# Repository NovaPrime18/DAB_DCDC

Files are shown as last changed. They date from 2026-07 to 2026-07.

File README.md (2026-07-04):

# 10kW Dual Active Bridge DC-DC Converter




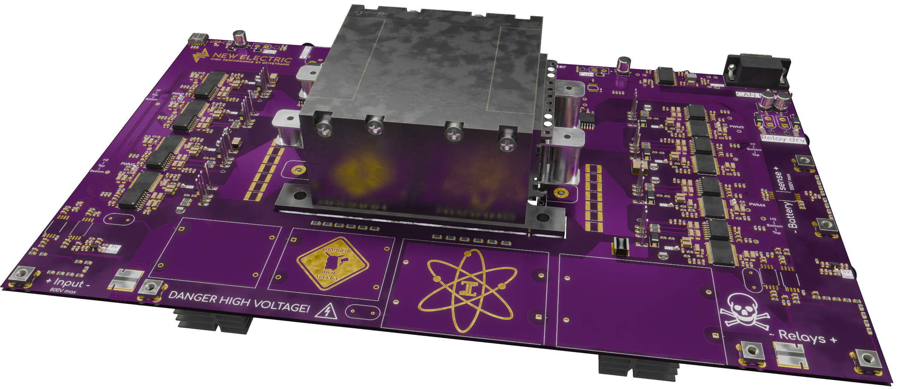
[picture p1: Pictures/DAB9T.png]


Hardware files for a high-power, high-frequency DC-DC converter PCB, developed as a
prototype module for a modular 500kW off-grid EV DC fast charger. The board implements
a Dual Active Bridge (DAB) topology with a planar transformer, isolated gate drivers and
sensing, and on-board water/air cooling provisions for the power stage.

This board is a single prototype module. Multiple modules are intended to be run in
parallel and/or series to scale up to the full 500kW system.

---

## Key specifications

| Parameter | Value |
|---|---|
| Topology | Dual Active Bridge (DAB) |
| Input voltage | 500–800V DC |
| Output voltage | 250–1000V DC (peak efficiency at 666V) |
| Output power | ~10kW per module |
| Output current | Primary 15A (22A peak), Secondary 17A (25A peak) |
| Switching frequency | 100kHz |
| Isolation | Galvanic, via transformer (10,000V dielectric strength primary/secondary) |
| Transformer | Payton Planar, 24:20 turns ratio, 35µH total leakage inductance |
| Control | TI controlCARD via CAN bus, phase-shift power regulation |
| PCB | 6 layers, 70µm (2oz) copper, 2mm FR4 |
| Secondary switches | Microchip MSC035SMA170B4 SiC MOSFETs (1700V) |
| Clearance / creepage | 3mm (primary) / 3.5mm (secondary), per IPC-2221 / IEC-60664 |
| Voltage derating | 1.7x on HV secondary components |
| Cooling | Fin-stack air-cooled heatsinks or aluminum liquid-cooling plate (SiCFETs + transformer) |
| Connectors | XT30 for HV in/out (contactors are off-board) |

## Board design notes

- All components are placed on the **top side only** for simpler, cheaper assembly; the
  transformer sits in the middle and physically supports the board (and the cooling plate,
  when fitted).
- Six copper layers at 70µm are used (instead of the reference design's 4 layers) to reduce
  conduction losses at higher secondary currents.
- HV secondary components are rated to 1700V to handle voltage spikes at the 1000V output
  target, with 1.7x derating.
- DC blocking capacitors are 2280-package, 1700V rated, double-stacked to reach the
  required capacitance. A future revision should move to the 3640 package, which has more
  capacitance per area but does not fit the current footprint.
- Contactors are **not** on the PCB — HV switching is handled externally via XT30
  connectors, allowing higher-voltage contactors to be selected independently of the board.
- Isolated 5V and gate-drive supplies are derived on-board; see "Known issues" below for a
  wiring correction needed for the secondary-side isolated 5V rail.
- Designed and manufactured through JLCPCB (6-layer, double-thick copper, 2mm FR4).
- 
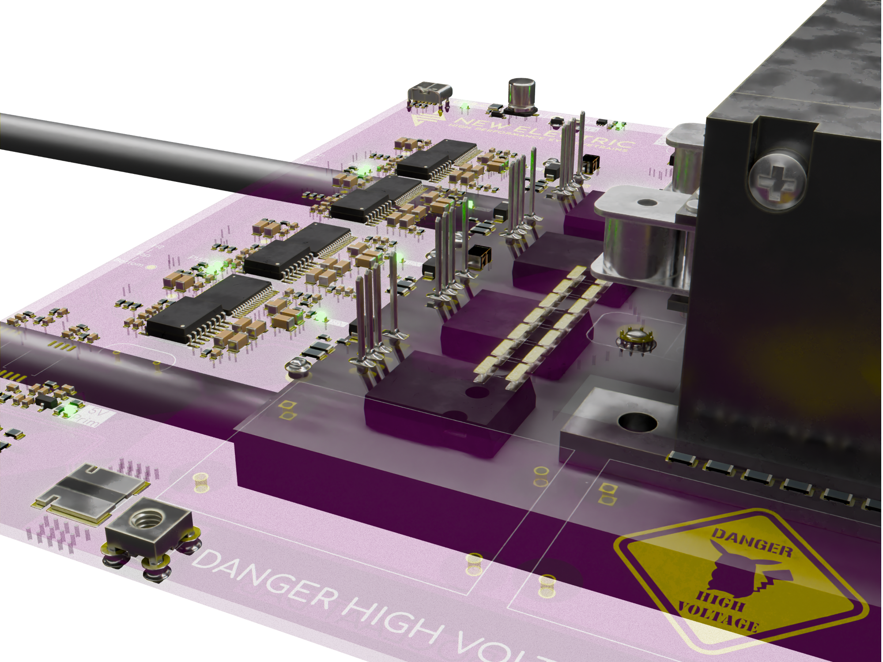
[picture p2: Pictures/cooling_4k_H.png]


## Design rule summary

These rules were applied during layout and should be followed in any revision:

- **High current:** ~1 via per amp for stitching/heat spreading, no 90° corner traces,
  70µm copper minimum, 6-layer stack-up. Trace rise kept to ≤10°C above ambient at 30A
  (verified with KiCad's trace-width calculator).
- **High frequency:** Ferrite-core planar transformer, short/direct high-frequency traces,
  minimized loop areas to limit EMI and parasitic inductance.
- **High voltage:** Clearance/creepage per IPC-2221 and IEC-60664 (3.5mm creepage at
  1000V), 2x voltage derating where practical, Plastik 70 conformal coating
  (>85kV/mm dielectric strength) on the assembled board.
- **Thermal:** Copper-filled vias, water-cooled or finned aluminum heatsinks on SiCFETs and
  transformer core.

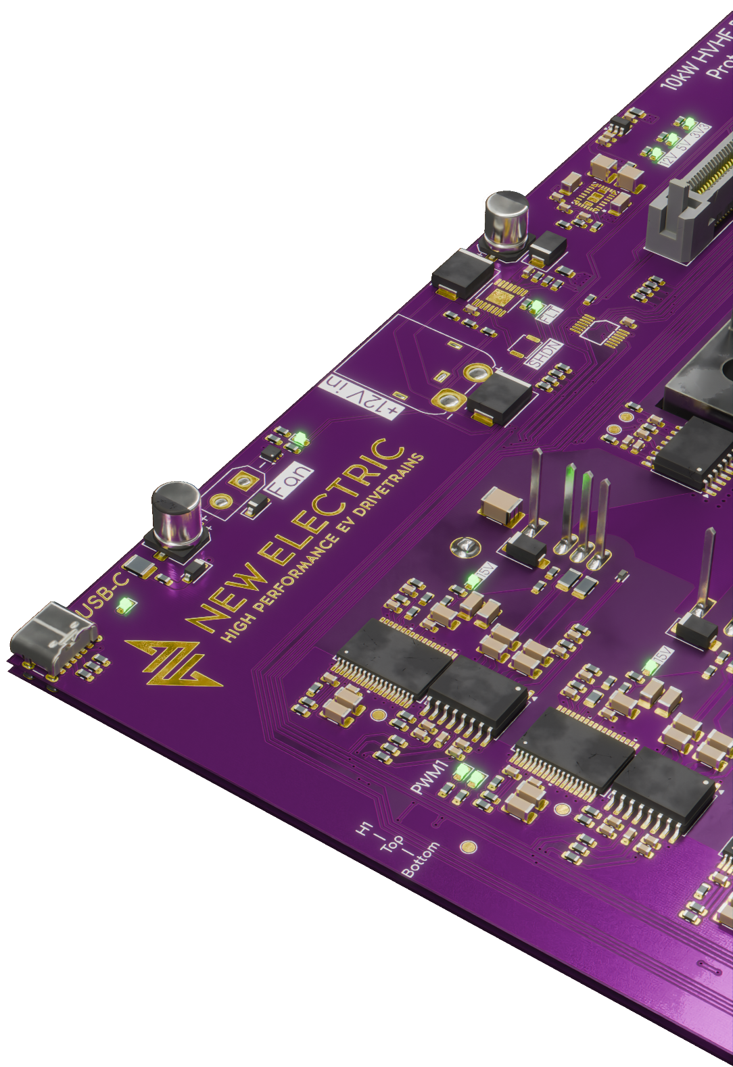
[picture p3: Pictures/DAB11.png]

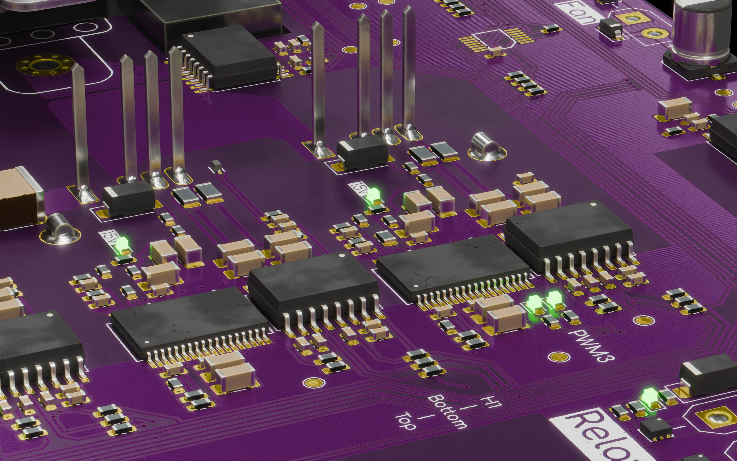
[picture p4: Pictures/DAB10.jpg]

## Known issues / errata (first prototype build)

These were found during assembly/bring-up of the first board and are **not yet fixed on
this design** unless noted — see schematics for full details:

- **eFuse (TPS26400):** Pins 3 and 5 were swapped in the footprint, preventing power-up.
  Fixed on the physical board with bodge wires; needs a schematic/footprint fix in the
  next revision.
- **controlCARD connector:** The standard KiCad/Digikey footprint for TI's connector has
  reversed pin numbering vs. TI's own controlCARD. A separate flip-adapter PCB is required
  as a workaround (included in this repo). The adapter should be ordered in 1mm board
  thickness, not 1.7mm, to avoid breaking the socket pins on connector insertion.
- **Isolated PSU current limit (Rlim):** Original 1k current-limit resistor caused
  overcurrent-protection faults on startup due to 5V rail capacitance. Change to 270R.
- **Primary-side sensing pinout:** DS modulator interface pins to the controlCARD were
  routed to pins that don't support DS modulators; rerouted with magnet wire on the
  prototype and needs correcting in the footprint/routing.
- **Secondary isolated 5V supply:** Originally derived from the "top" isolated supply of
  H2, whose ground floats to 1000V half the switching cycle. Must be re-derived from the
  "bottom" isolated supply of H2 instead.
- **Cooling clearance:** Backside DC capacitors interfere with the aluminum cooling plate;
  stack capacitors on the top side instead. The transformer cutout also needs enlarging —
  it's currently a tight fit.

⚠️ Due to the eFuse/pinout bodges above, **this specific assembled prototype should only
be tested at low voltage (LV), not at its rated HV**, until a corrected revision is built.

## Repository contents

- Schematics and PCB layout (KiCad)
- Fabrication outputs (Gerbers / stencil) as ordered from JLCPCB
- controlCARD adapter PCB (flips connector pinout, 90° mount)
- Renders of the assembled board and cooling solutions

## Background

This board was developed as part of an internship thesis evaluating the feasibility of
in-house production of a 500kW off-grid EV DC fast charger, based on and enhanced from a
Texas Instruments DAB reference design. Full design rationale, simulation results
(LTspice/PLECS), and test results are documented in the accompanying thesis — this README
covers only the PCB/hardware side.

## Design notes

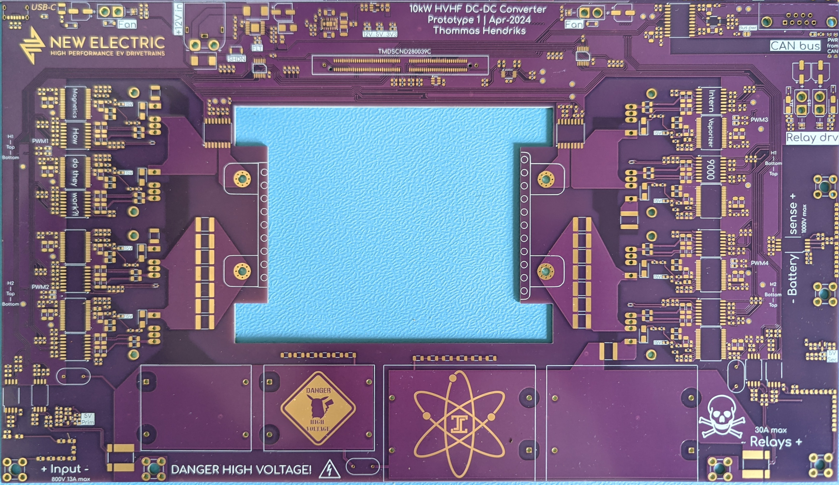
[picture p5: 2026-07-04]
Pictures/irlpcb.jpg

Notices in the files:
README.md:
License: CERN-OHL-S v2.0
